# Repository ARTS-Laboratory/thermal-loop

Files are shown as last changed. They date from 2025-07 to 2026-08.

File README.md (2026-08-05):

# CORE²S
## Control-Oriented Research Environment for Energy Systems

A physical and digital testbed for experimenting with thermal, fluid, and control behavior in energy systems. It supports model calibration, dynamic synchronization, and validation of control strategies using measured loop data and simulation.

<p align="center">
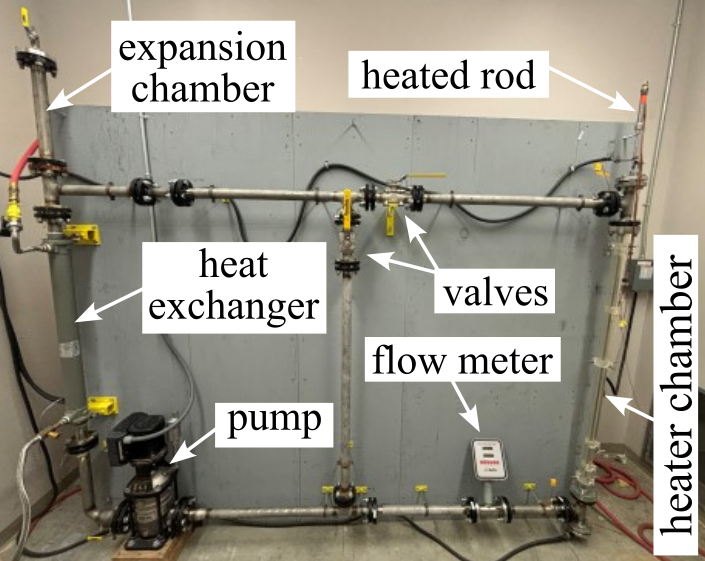
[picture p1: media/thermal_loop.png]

</p>
<p align="center"> Pressurized thermal loop with key components annotated.
</p>

## Licensing and Citation

[][cc-by-sa]

This work is licensed under a
[Creative Commons Attribution-ShareAlike 4.0 International License][cc-by-sa].

[cc-by-sa]: http://creativecommons.org/licenses/by-sa/4.0/
[cc-by-sa-image]: https://licensebuttons.net/l/by-sa/4.0/88x31.png
[cc-by-sa-shield]: https://img.shields.io/badge/License-CC%20BY--SA%204.0-lightgrey.svg

Cite as:

@Misc{ARTSLabControlOrientedResearch,
  author = {{ARTS-L}ab},  
  note   = {Accessed: 20xx-xx-xx},   
  title  = {Control-Oriented Research Environment for Energy Systems},   
  year   = {20xx},   
  groups = {{ARTS-L}ab},   
  url    = {https://github.com/ARTS-Laboratory/core2s},   
}

<p align="center">
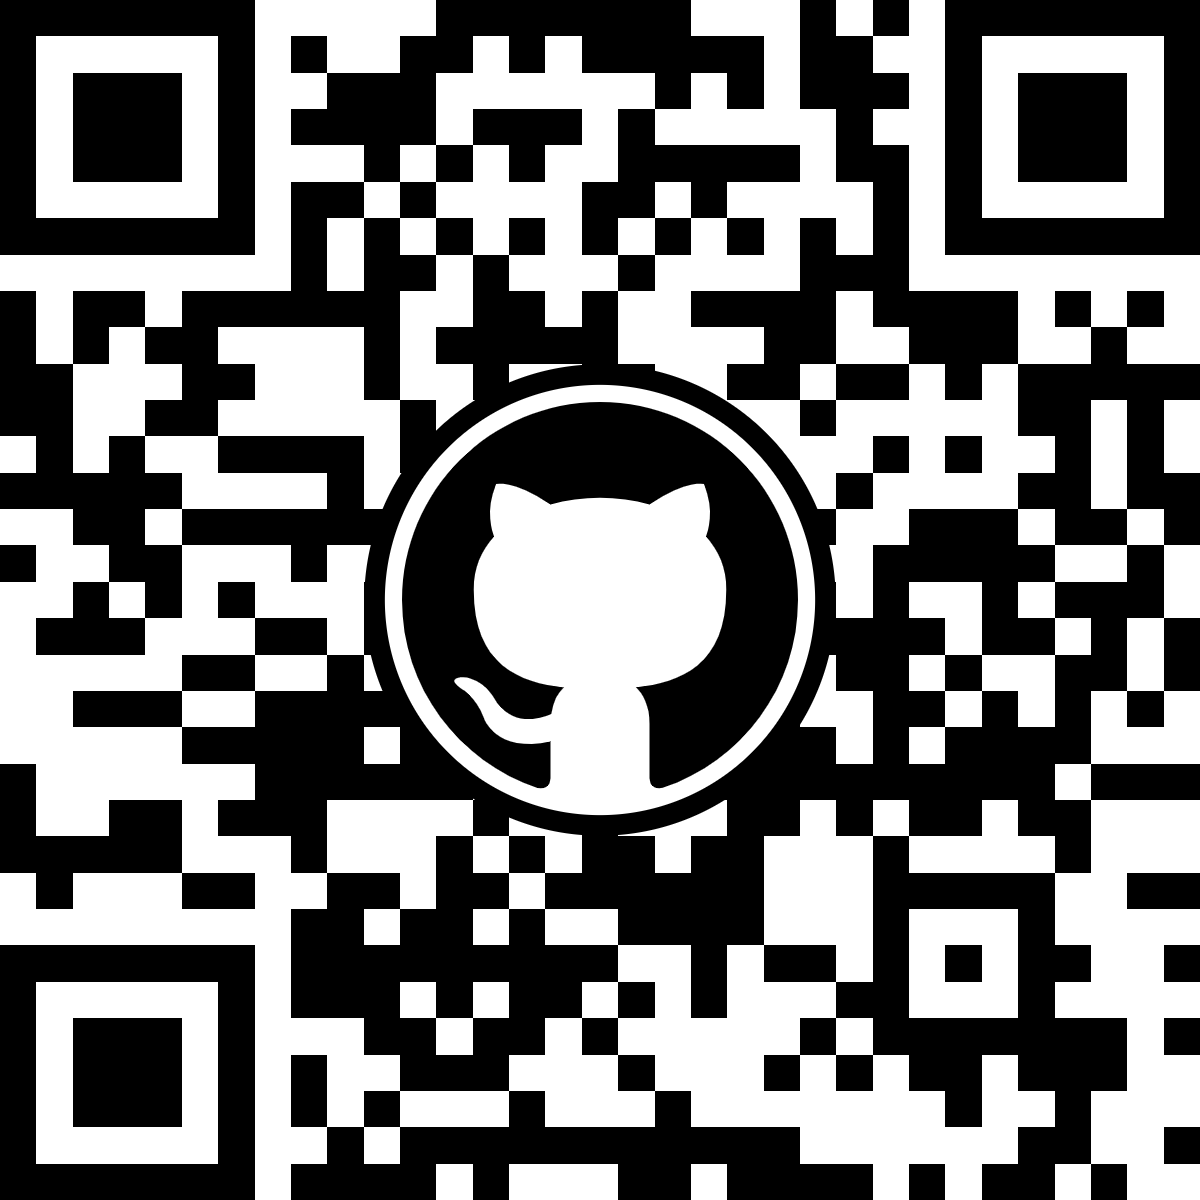
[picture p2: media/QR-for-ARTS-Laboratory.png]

</p>
<p align="center">
QR code for repo.

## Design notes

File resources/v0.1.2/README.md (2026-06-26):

# v0.1.1

## CAD

## Data

## Sesign Documents

## Controller

## Simulations

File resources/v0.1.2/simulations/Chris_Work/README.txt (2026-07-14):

This folder contains the work of Chris Heaps on simulations of the SMR loop in Simscape. Versions are detailed as follows:

v1.0.1: First working model, uses constant energy supply to the fuel rod and constant city side water supply temperature

v1.0.2: Adds transient initial conditions for the loop. This includes a function to represent slight variations in the city water supply temperature. Also adds a direct voltage input for the heat supplied to the simulated fuel rod, just as the actual loop has.

v1.0.3: Retains the same features as previous model and adds controllable power supply for varying voltages. This is the most stable and accurate version of the model so far. Longest test has been twelve hours and it maintained the cutoff temperature almost perfectly throughout the main loop for the entire test.

Next versions: Redesign for incorporation with SpeedGoat real time target computer.

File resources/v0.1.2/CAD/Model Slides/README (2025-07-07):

In this folder, there are the slides to the final model as well as the extension pipes we used to expand our current Thermal Loop System. We have included both the threaded and welded versions of the one foot extension pipe.

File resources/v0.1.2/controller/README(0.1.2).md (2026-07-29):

# Controller Code

* The LabVIEW Controller code
* **LabVIEW\_SMR\_V1:**
* 
* First iteration of the LabVIEW for the thermal loop, completed 6/24/26.
* 
* Only goals of this was to confirm that values are being read from the heat exchanger, all 7 pressure transducers, and all 8 thermocouples.
* 
* Problems to fix:
* 
* Incorrect flow meter value (around 0.2 GPM too high)
* 
* Incorrect P4 measurement, as well as possibly others incorrect as well
* 
* Temp. And Pressure graphs not reading history of each different sensor, instead combining them into one function
* 
* No labels on the array of outputs
* 
* To be added in future iterations:
* 
* proportional valve showing and PID control established
* 
* Possibly flow meter in main loop wired to show readings as well (will need to investigate further to see about buying a new one or if able to wire to current)
* 
* &#x20;
* 
* **LabVIEW\_SMR\_V2:**
* 
* Focused on fixing problems from first iteration:
* 
* Pressure not reading correctly (deep dive into P4 wiring still required, possibly not a LabVIEW problem)
* 
* Graphs fixed
* 
* Compensator attempted to be added to fix incorrect flowmeter output, although needs to be fine tuned (possibly with a function?)
* 
* Arrays fixed so that labels for data points are visible

**LabVIEW\_SMR\_V3:**

Focused on fixing problems from second iteration:

Pressure reading for P4 fixed

Temperature and Pressure readings split into:

&#x09;Main loop (loop excluding heat exchanger) average pressure/temp, heat exchanger average pressure/temp, and overall (loop + heat exch.)

&#x09;average pressure/temp

Still a problem with flowmeter not being calibrated correctly, will need to be fixed in future iterations

For now, looks like flowmeter is only data reading that is incorrect.

Future iterations: adding proportional valve and working through control for it

&#x09;		adding a storage system, where the data is stored directly into a file for future use.

**LabVIEW\_SMR\_V4:**

First iteration with rudimentary Proportional Valve control attempted

control DOES NOT WORK!

**LabVIEW\_SMR\_V4.5:**

Second iteration with Proportional Valve control attempted. still does not work, but diagnosed the physical controller as the problem

**LabVIEW\_SMR\_V5:**

No proportional valve added, only attempted to create a data storage system, throwing data into 3 different .csv 's: one for temp, one for pressure, one for heat exchanger flow.

Broke everything, does not work, currently in progress.

**LabVIEW\_SMR\_V6:**

Complete data acquisition and automatic file storage

Data is stored into SMR\_Logs folder on local computer in c004. If using a different computer, file path on the front panel must be changed to your specific location.

**LabVIEW\_SMR\_V6.5:**

Changed V6 so that there is now one file path name instead of three. all data is now saved into the GitHub folder data -> 001 -> run\_\[data of test]. Paired with Python, python will also insert plots of the data directly into this run folder.

**LabVIEW\_SMR\_V6.75:**

Changed V6.5 so that warning lights are added: 3 different red lights showing if max pressure was reached, max temp was reached, or max voltage was reached (respectively). All have controllable thresholds via the front panel.

Added a steady state indicator, with a controllable threshold. Green light turns on when steady state is reached, which is calculated via (deg C/min).
To be added in next version: voltage readings via new cDAQ NI 9229.

**LabVIEW\_SMR\_V7:**

First version with working (manual) proportional valve control. Although rudimentary, valve can be controlled via "P-Valve Command Voltage) from 0-10V.

For next iteration:

&#x09;add emergency shut off (if temp reaches \_\_, open p-valve all the way, etc.)

&#x09;add PID control for p-valve

&#x09;add voltage reading (when cables acquired)

**LabVIEW\_SMR\_V7.1:**

Rudimentary PID control for P-valve established. On/Off switch to determine whether manual or PID control takes over p-valve voltage.

Next iteration:

&#x09;tune PID and limit the p-valve (flow meter only goes to 5GPM, need to limit how far the valve opens)

**LabVIEW\_SMR\_V7.2:**

Nothing with valve changed.

Steady state indicator fully upgraded; works like this:

&#x09;When running, system waits 5 minutes for system to heat up

&#x09;After 5 minutes, the system calculates the maximum dT/dt in that 5 minute window

&#x09;Maximum dT/dt is multiplied by 0.01 (1%)

&#x09;1% of the maximum dT/dt is considered to be the steady state threshold

&#x09;Loop continues to run, data continues to collect. When \[current dT/dt] < \[steady state threshold], system is considered to be in steady state.

**LabVIEW\_SMR\_V7.3: CURRENT BEST MODEL**

Revamped front panel to make it easier to interpret data as system is running. Also better grouping of indicators.

**LabVIEW\_SMR\_V7.5: CURRENT BEST MODEL**

Added indicator for voltage across rod. DO NOT TRUST THE POWER SUPPLY READINGS, ONLY LABVIEWS: PSU indicates higher voltage than what is physically going across rod; resistance and general voltage drop results in about 1-1.5V lost to the rod.

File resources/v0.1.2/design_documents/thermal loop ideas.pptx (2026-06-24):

## SMR Thermal Loop Ideas

Austin Downey

## The main idea

Keep it,
- Safe
- Simple
- Easy
- Clean

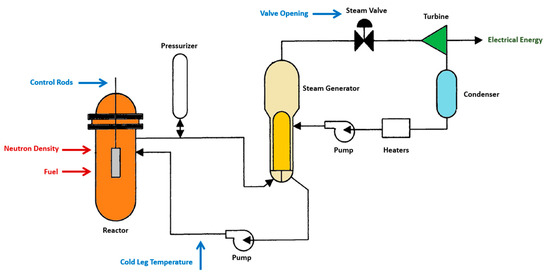
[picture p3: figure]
Energies 15 06588 g005 550

Basic idea, from the paper “Real-Time Simulation of a Small Modular Reactor in-the-Loop within Nuclear-Renewable Hybrid Energy Systems”
https://www.mdpi.com/1996-1073/15/18/6588

## Our version

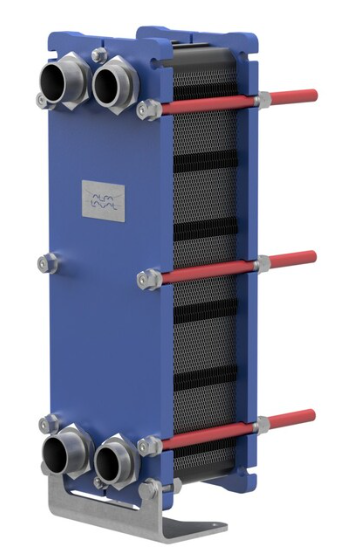
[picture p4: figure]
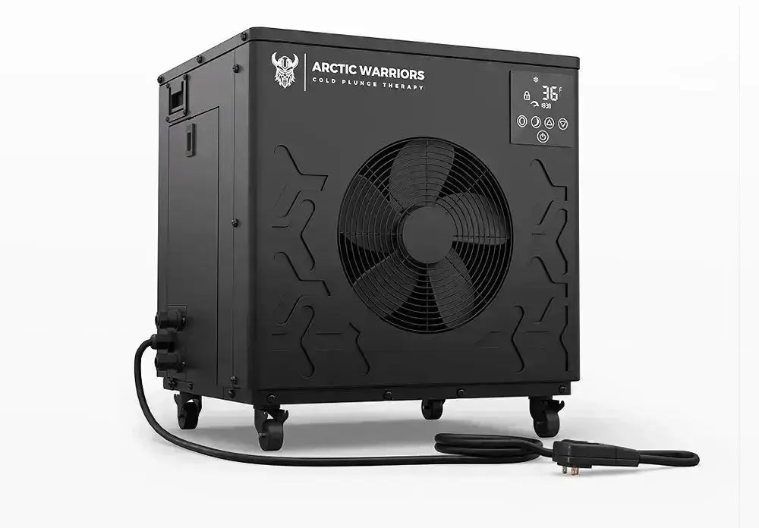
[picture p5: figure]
Arctic Warrior 0.5 HP Advanced Water Chiller Arctic Warriors

chiller

Plate heat exchanger

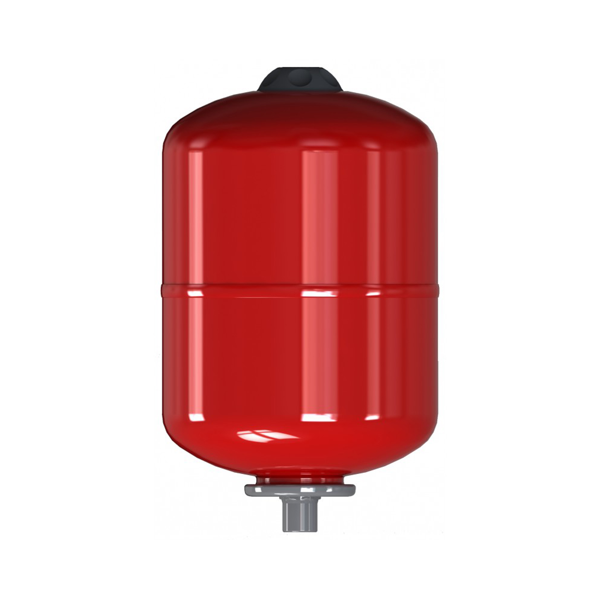
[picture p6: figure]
Varem 90 psi Max (20 psi Precharged) 10.6 gal. Expansion Water Heater Tank, 0.75 in. Inlet Diameter 1581106

pressure tank

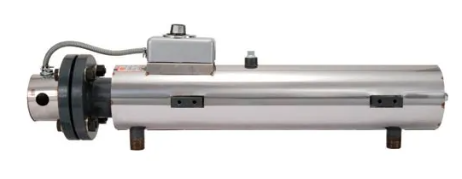
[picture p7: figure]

Inline heater

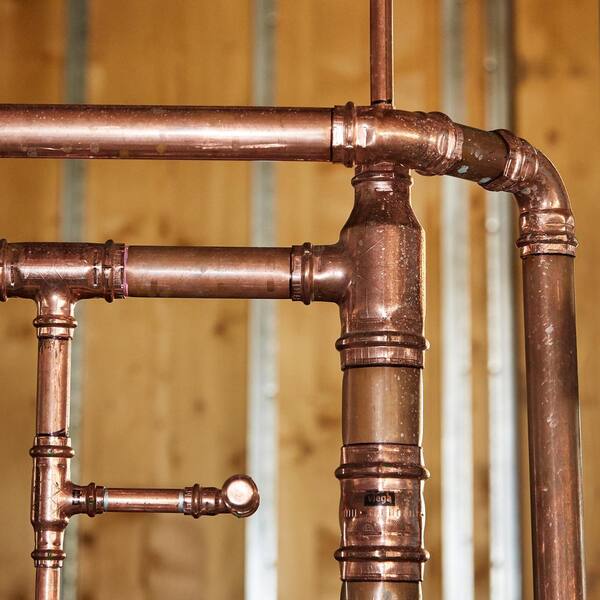
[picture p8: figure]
Viega 77477 ProPress 2 in. Press Copper Tee

2” pro press line

## Hardware we have for use

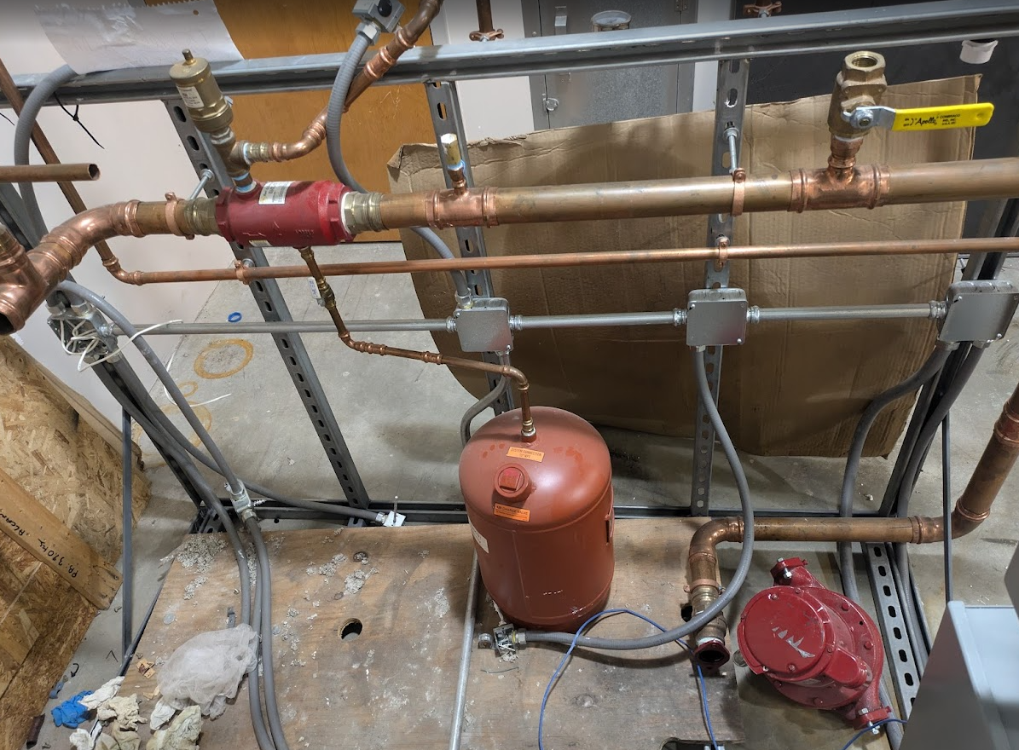
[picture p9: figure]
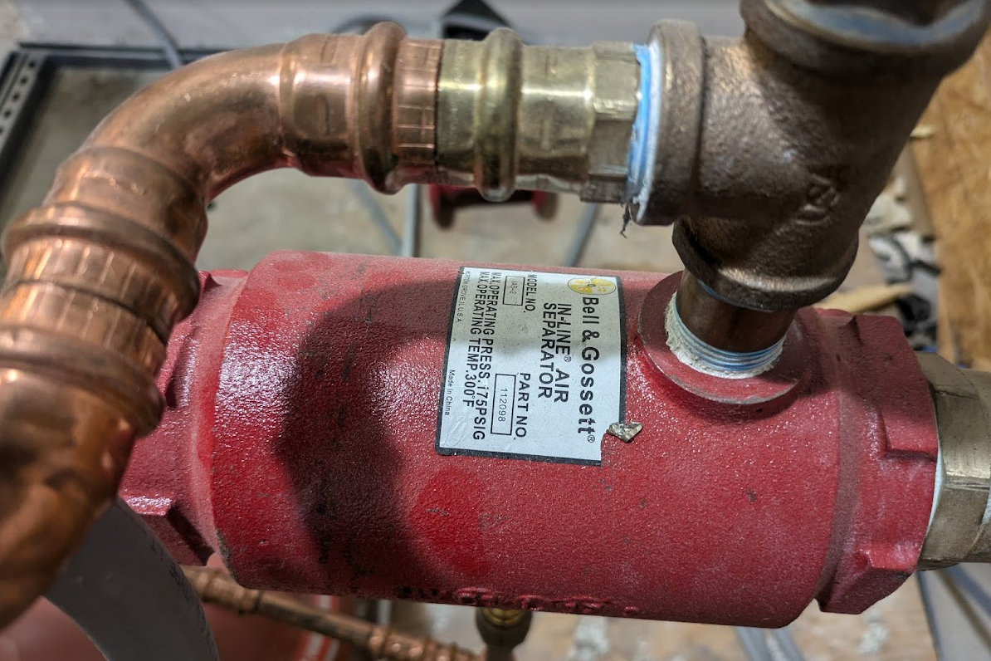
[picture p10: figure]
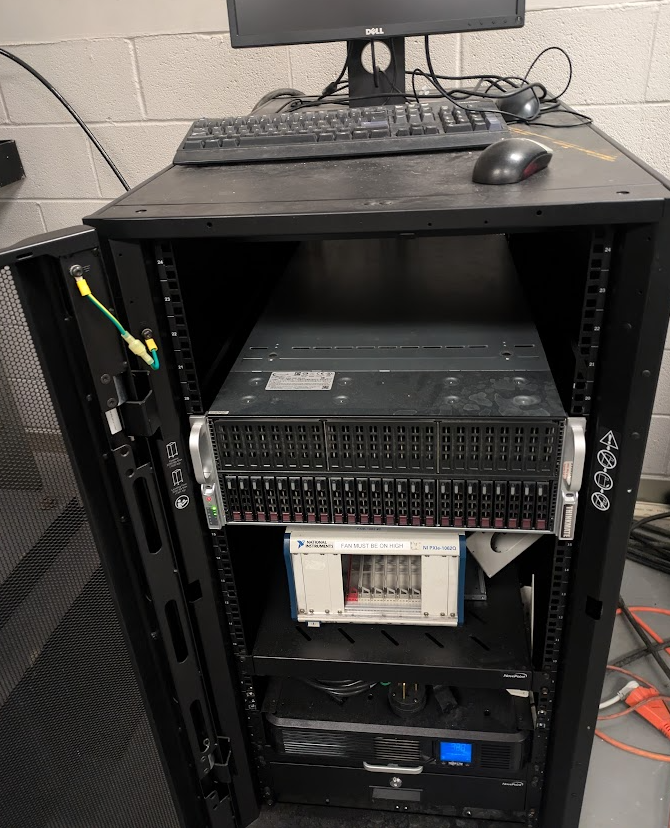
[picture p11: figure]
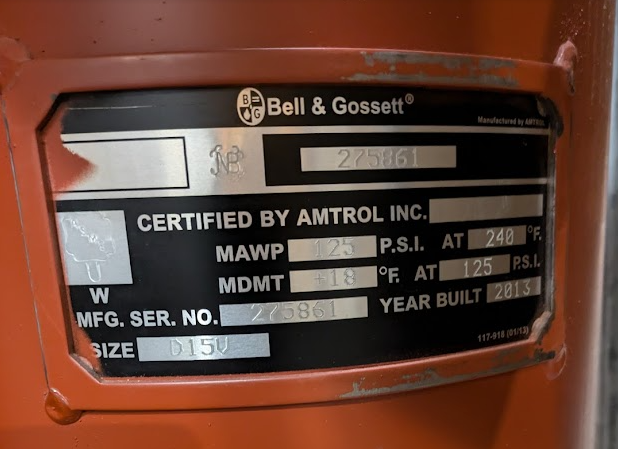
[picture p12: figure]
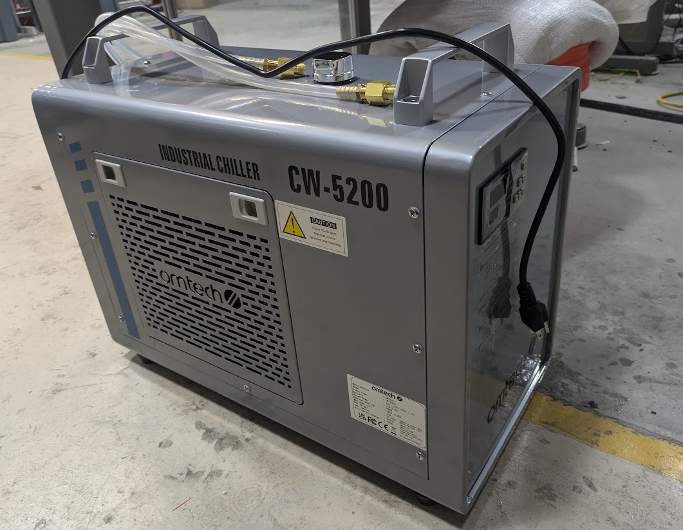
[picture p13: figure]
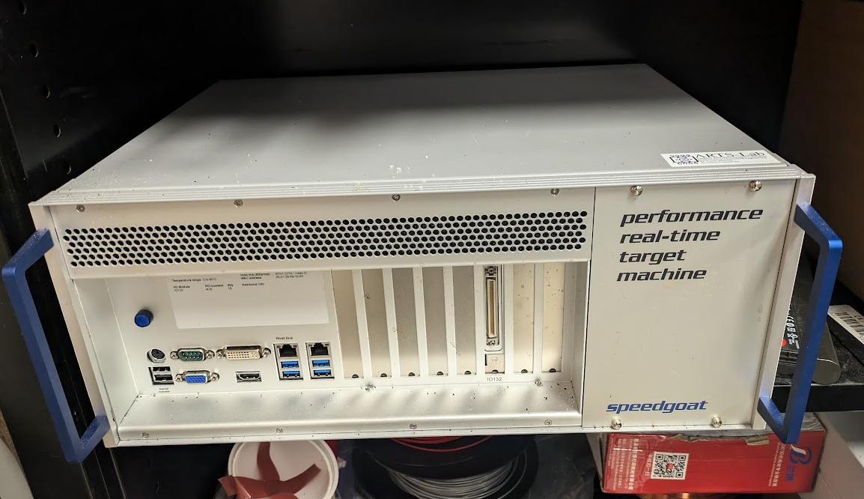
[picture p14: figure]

## Hardware we have for use

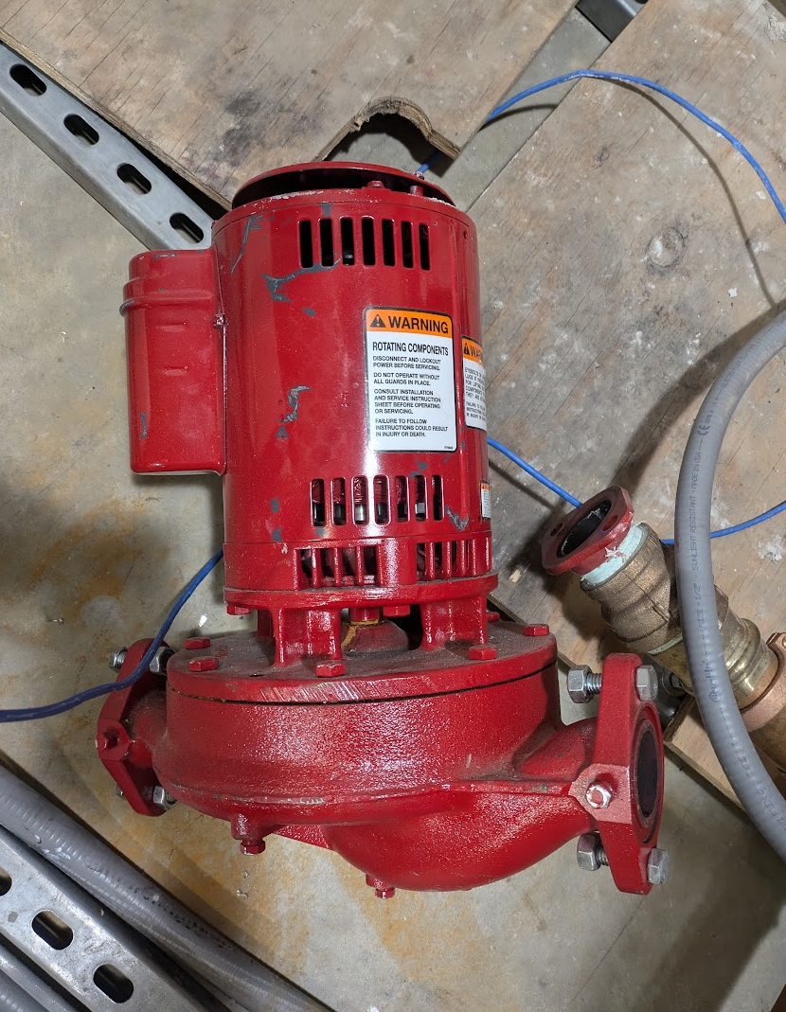
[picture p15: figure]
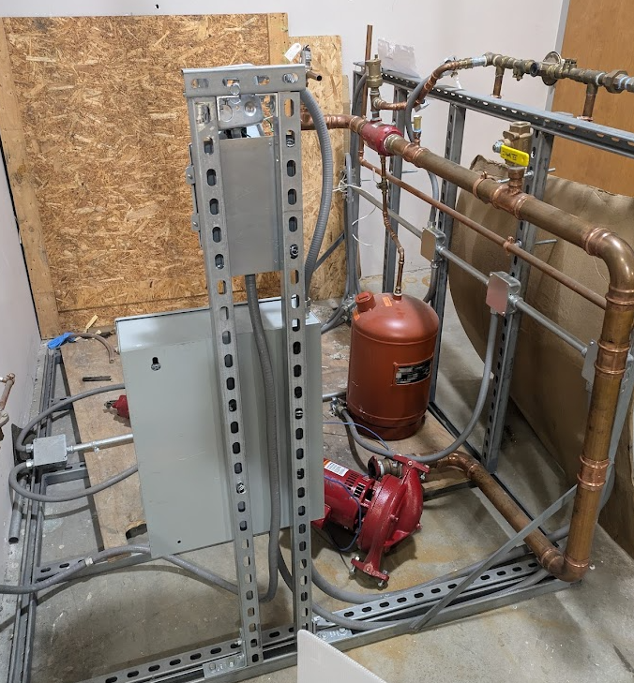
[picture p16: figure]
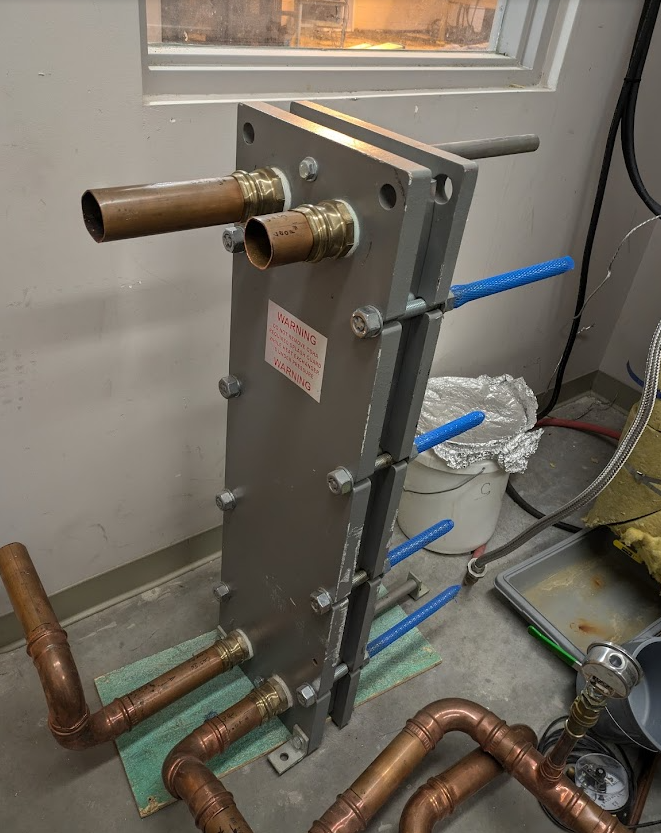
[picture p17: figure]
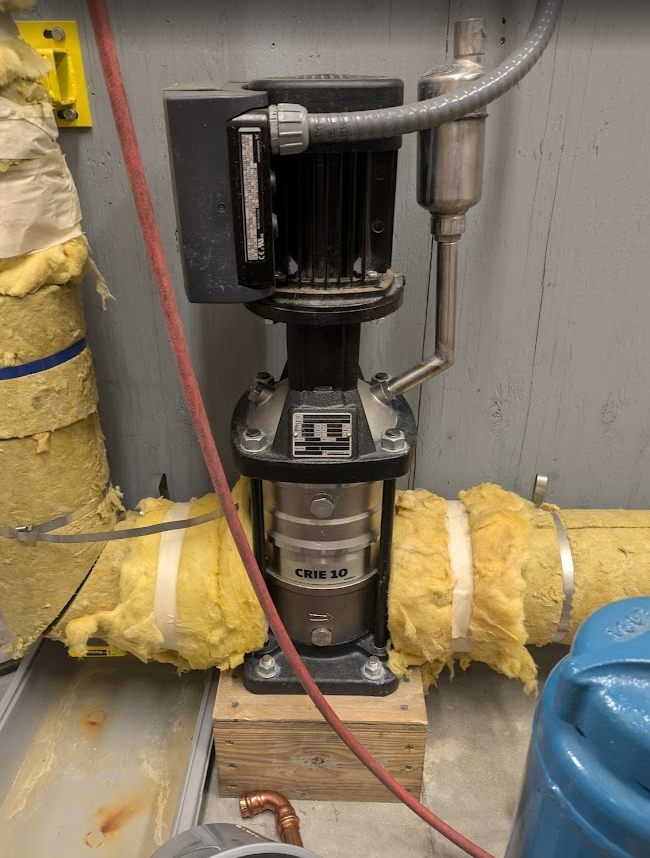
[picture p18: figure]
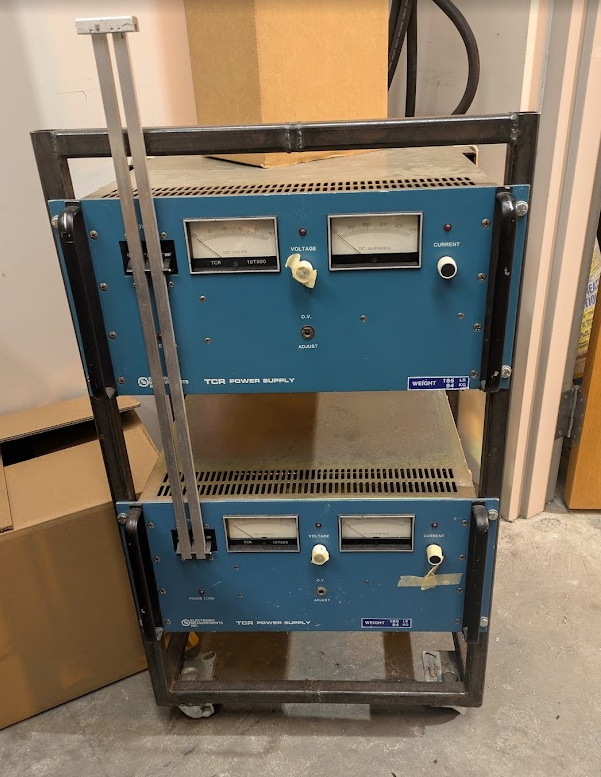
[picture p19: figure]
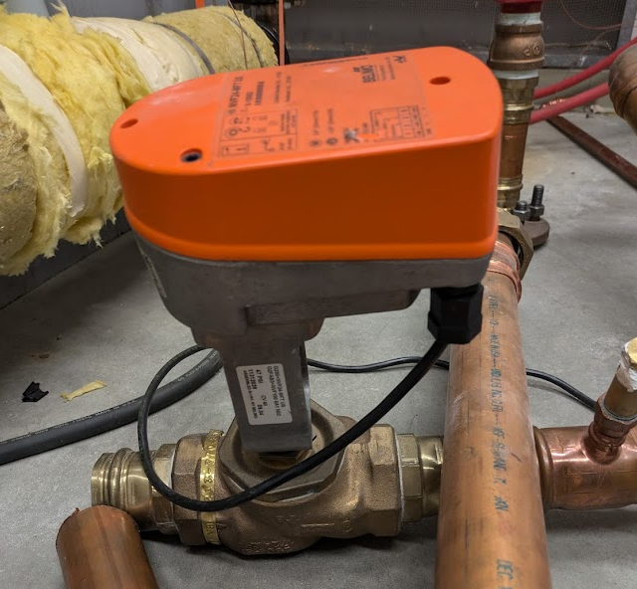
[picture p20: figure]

## Thank You for Your Time

- Name: Ausitn Downey
- Title: Associate Professor
- Email: austindowney@sc.edu
- Lab GitHub: github.com/arts-laboratory

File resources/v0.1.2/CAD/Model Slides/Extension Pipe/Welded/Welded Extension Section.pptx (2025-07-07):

## Welded Extension Section

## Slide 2

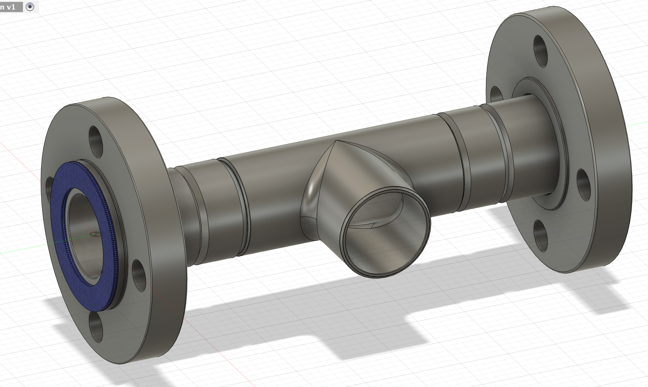
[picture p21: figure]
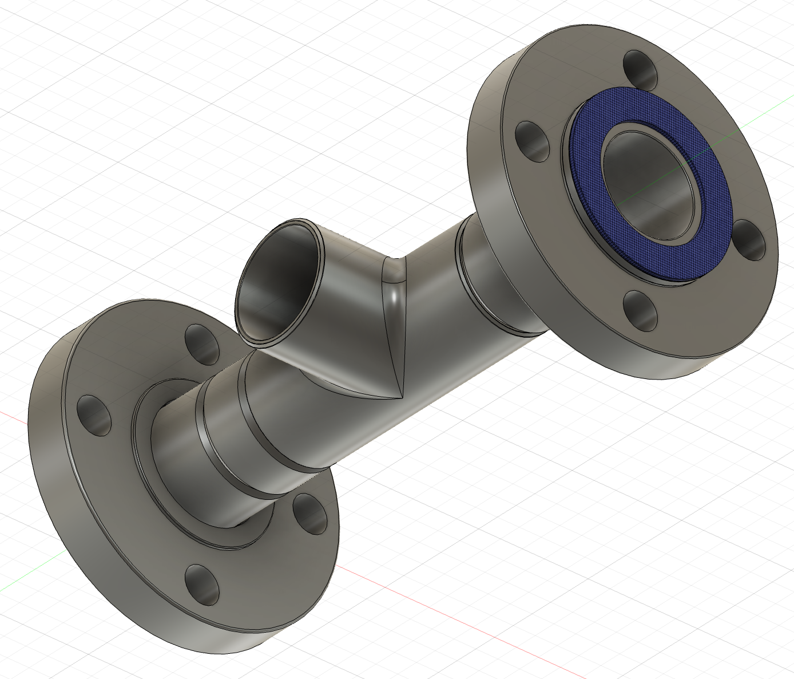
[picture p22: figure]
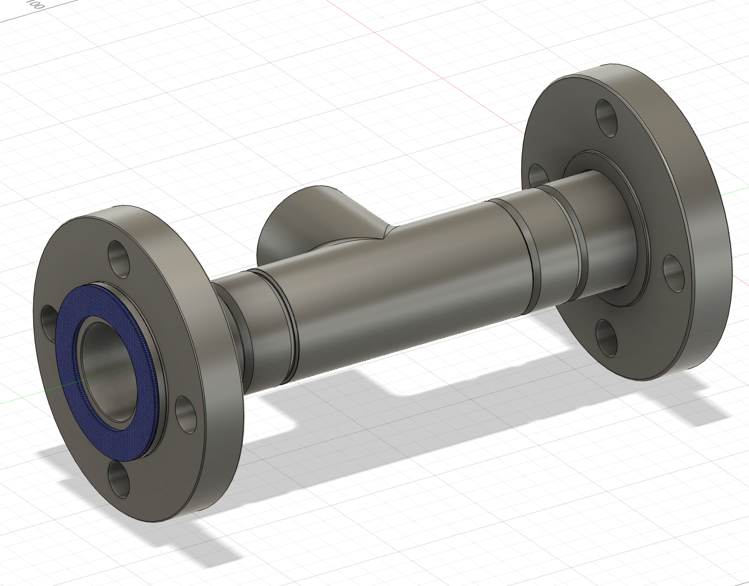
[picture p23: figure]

Complete Welded Extension

Cost
(Flanges) 2 x $63.10 = $126.2
(Pipes) 2 x $58.98 = $117.96
(Flng Pipes) 2 x $75.45 = $150.90 +
(T-Pipe)1 x $44.86 = $44.86
(Seal) 2 x $10.97 = $21.94
Total cost ========== $461.86

Length = 267.4 mm

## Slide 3

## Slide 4

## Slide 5

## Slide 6

Welded Flange

Cost
$63.10 each
2 flanges used
Total = $126.2

Welded Flange Grainger Link (https://www.grainger.com/product/Pipe-Flange-Slip-On-Flange-60WJ84)

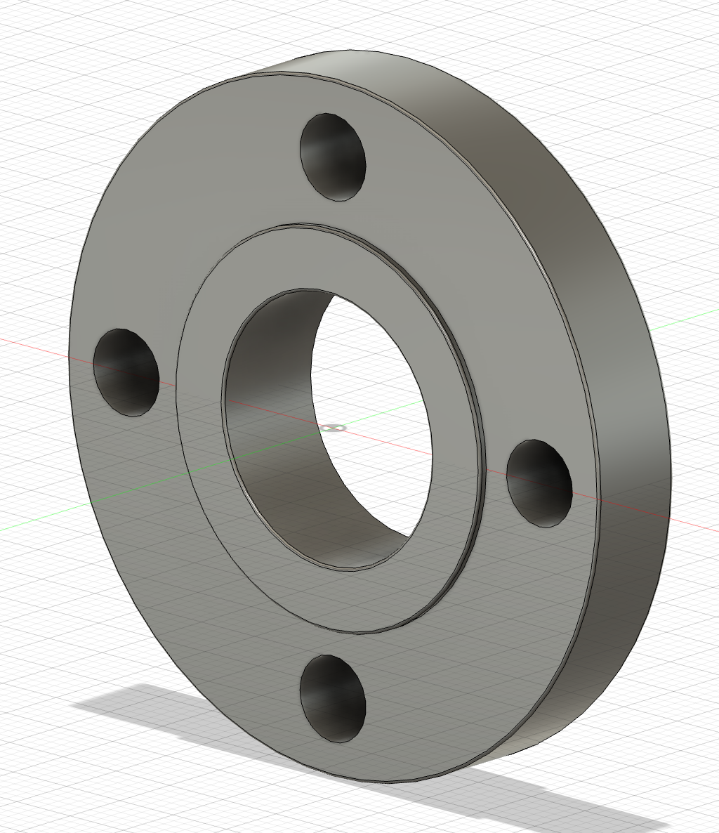
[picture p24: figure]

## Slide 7

1 ½ Weld Extension Pipe

Cost
$58.98 each
2 pipes used
Total = $117.96
This pipe is a custom-cut 23.8 mm
piece a 1 ft long pipe

Welded pipe Grainger Link (https://www.grainger.com/product/Nipple-304-Stainless-Steel-782G43)

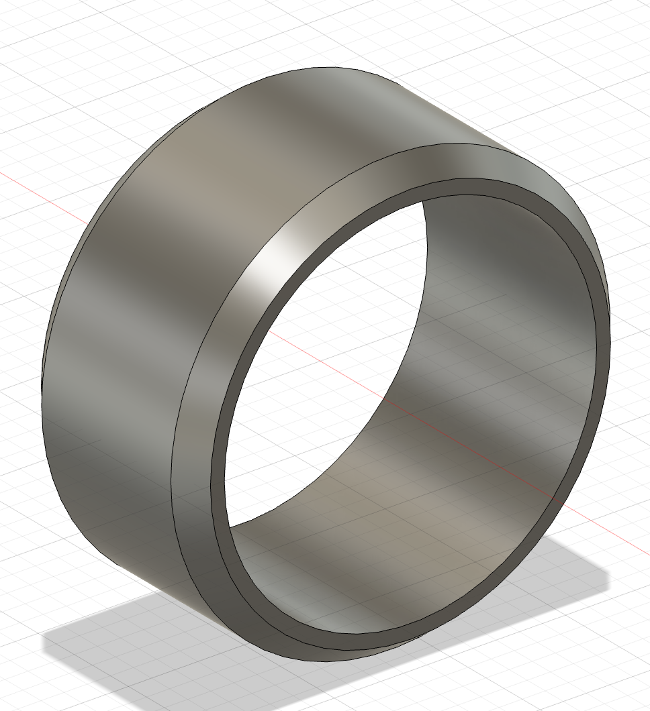
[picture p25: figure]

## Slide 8

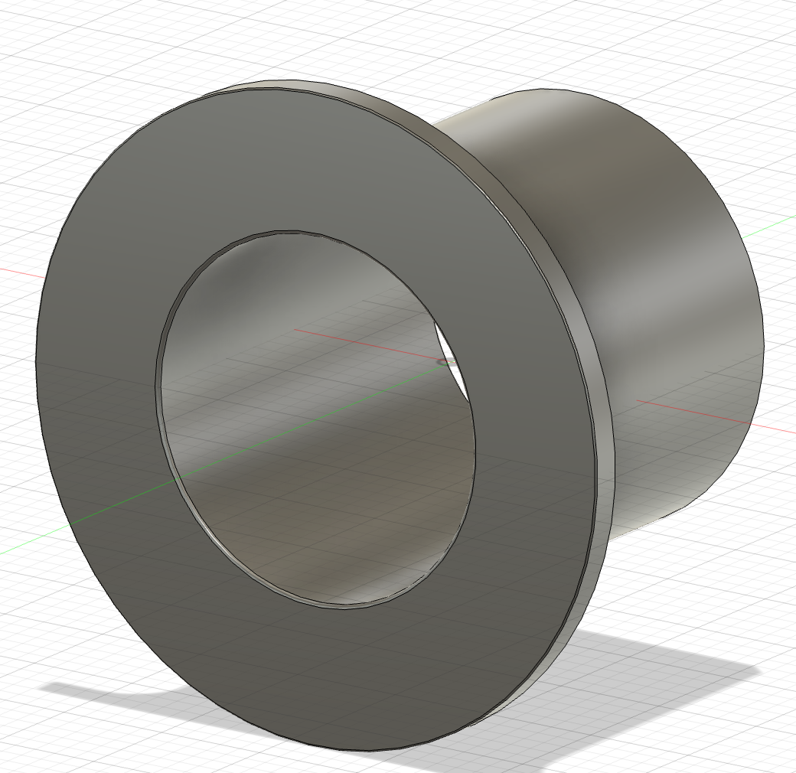
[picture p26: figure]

Flange Step End Pipe

Cost
$75.45 each
2 Flange Pipes used
Total = $150.90

Step End Pipe Graigner Link (https://www.grainger.com/product/Stub-End-Type-A-304L-Stainless-1RTU2)


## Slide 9


Welded T-Pipe

Cost
$44.86 each
1 T-Pipe used
Total = $44.86

Welded T-Pipe Grainger Link (https://www.grainger.com/product/Tee-304L-Stainless-Steel-1RTR2)


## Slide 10

Average Flange Blue Seal

Cost
$10.97 each
2 seals used
Total = $21.94


Flange Seal Grainger Link (https://www.grainger.com/product/GARLOCK-Ring-Flange-Gasket-Class-150-38VR20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)

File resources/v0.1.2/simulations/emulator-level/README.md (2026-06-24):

# Multi-domain Models

## Emulator Level
* A Simscape model of the thermal loop as built in C004G
* Used for developing a DT of the thermal loop

### What follows if from MAtt's upload. 
* Update as needed. 
**PRESSURIZED WATER REACTOR FOR A SMALL MODULAR REACTOR**

The models here conatain variations of a thermal loop for a pressurized water reactor system in a small modular reactor. 
The thermal loop consists of 2 main cycles;

~primary - the loop containg the fluid flow through the reactor to the steam generator

~secondary - the loop used to generate electricity from the steam in the steam generator


citation link; https://www.nrc.gov/reading-rm/basic-ref/students/animated-pwr.html 

[text](../README.md)

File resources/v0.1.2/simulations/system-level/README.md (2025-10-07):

# System Level
* An expansion of the emulator loop to include perifierity components like reactors, steam generators, and turbines
* Used for developing a system-level understanding of how the emulator interacts with the broader grid.

* 

This is the part of the image highlighted in blue

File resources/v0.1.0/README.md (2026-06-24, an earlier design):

# v0.1.0
* All files for the initial system
* Covers work done in the summer of 2025-june 2026
* Has a collectoin of CAD files, data, code, etc.

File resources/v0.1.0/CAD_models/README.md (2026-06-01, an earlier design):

# CAD models

* V0.1.0 - CAD models done in the summer of 2025 by summer High School Students 
* V0.1.1 - CAD models integrated into Inventor Ecosystem

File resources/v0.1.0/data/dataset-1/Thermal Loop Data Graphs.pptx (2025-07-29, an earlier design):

## Thermal Loop Data Graphs

## Test #1: Pump Heat up (vo)


PDF name- Full_PumpHeat(HeatExchange.flow.vo)

- Middle valve open
- Upper valve open
- Heat exchange increments of 0.5 gal/min every 30 mins starting at hour 6

Raw Data File name
PumpHeat_HeatExhanger.flow.vo

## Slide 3

Test #1: Additional close up data


PDF name- PumpHeat_up_6_hours.vo


0.511 gal/min flow rate

1.022 gal/min flow rate

1.500 gal/min flow rate

2.001 gal/min flow rate

PDF name- PumpHeat_HeatExchange.flow.vo

## Test #2: Pump Heat up (vc)


PDF name- Full_PumpHeat(HeatExchange.0.5flow.vc)

- Middle valve closed
- Upper valve open
- Heat exchanger 0.5 gal/min flow rate at 6 hours

Raw Data File name PumpHeat_HeatExchanger.0.5flow.vc

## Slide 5

Test #2: Additional close up data


PDF name- PumpHeat_HeatExchange_0.5gal._flow.vc


PDF name- PumpHeat_up_6_hours.vc

0.511 gal/min flow rate

## Test #3: Rod Heat up (vc)


PDF name- Full_RodHeat(HeatExchange.flow.vc)

- Middle Valve closed
- Upper Valve open
- Heat Exchanger 0.5 gal/min at 4.5 hours

Raw Data File name
RodHeat_NewData

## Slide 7

Test #3: Additional close up data


PDF name- RodHeat_0.5_gal_flow.vc


PDF name- RodHeat_6_hours.vc

0.511 gal/min flow rate

## Test #4: Rod Heat up (vo)


PDF name- Full_RodHeat.vo(CoolDown)

- Middle Valve open
- Upper Valve open
- At 4.45 hours Pump and Rod turned off

Raw Data File name
RodHeat_vo_cool_NewData

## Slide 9

Test #4: Additional close up data


PDF name- RodHeat_CoolDown.vo

PDF name- RodHeat_up.vo

Pump and Rod turned off

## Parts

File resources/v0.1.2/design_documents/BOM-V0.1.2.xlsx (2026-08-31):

Internal Part Name | MFR / Vendor Description | MFR Part Number | Quantity | Individual Cost | Total Cost | Notes | Vendor 1 | Vendor 2 | Vendor 3 | Vendor 4
Wire Duct | Thomas & Betts - 2 X 2 X 72 IN GRAY WIDE SLOT WIRING DUCT | MSC Direct | 92012988 | 1 | 25.58 | $25.58 |  | https://www.mscdirect.com/product/details/92012988?rItem=92012988
Hex Screw | Value Collection - Hex Head Cap Screw: 5/8-11, 3" Length Under Head, Grade 2 Steel, Zinc Finish | MSC Direct | 67436964 | 10 | 1.71 | $17.10 |  | Value Collection - Hex Head Cap Screw: 5/8-11, 3" Length Under Head, Grade 2 Steel, Zinc Finish | MSC Direct (https://www.mscdirect.com/product/details/67436964?rItem=67436964)
Hex Nut | Value Collection - Hex Nut: 5/8-11, Grade 2 Steel, Bright/Uncoated Finish | MSC Direct | 67473967 | 10 | 0.47 | $4.70 |  | Value Collection - Hex Nut: 5/8-11, Grade 2 Steel, Bright/Uncoated Finish | MSC Direct (https://www.mscdirect.com/product/details/67473967?rItem=67473967)
Wire Duct | 1.50" x 0.75" x 6' White Lead-Free PVC Panduct® Narrow Slot Wiring Duct | Fastenal | 99176795 | 6 | 5.45 | $32.70 |  | 1.50" x 0.75" x 6' White Lead-Free PVC Panduct® Narrow Slot Wiring Duct | Fastenal (https://www.fastenal.com/product/details/99176795)
Wire Duct | 1 1/2 in Nom Wd, 1.3 in Slot Ht, Wiring Duct - 53UJ14|TYD15X2NPG6 - Grainger | 53UJ14 | 3 | 25.94 | $77.82 |  | 1 1/2 in Nom Wd, 1.3 in Slot Ht, Wiring Duct - 53UJ14|TYD15X2NPG6 - Grainger (https://www.grainger.com/product/53UJ14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)
Duct Cover | PVC, 72 in Lg, Wiring Duct Cover - 53UH83|TYD15CPG6 - Grainger | 53UH83 | 3 | 10.41 | $31.23 |  | PVC, 72 in Lg, Wiring Duct Cover - 53UH83|TYD15CPG6 - Grainger (https://www.grainger.com/product/53UH83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)
Threaded Flange | Flange, 304 Stainless Steel, Metal Pipe Flange - 4WPV1|4381001040 - Grainger | 4WPV1 | 1 | 93.93 | $93.93 |  | Flange, 304 Stainless Steel, Metal Pipe Flange - 4WPV1|4381001040 - Grainger (https://www.grainger.com/product/Metal-Pipe-Flange-Flange-4WPV1)
Plastic Bushing | Bushing, 1 1/2 in x 3/4 in Fitting Pipe Size, Pipe Straight - 1MKC2|RB150-075 - Grainger | 1MKC2 | 1 | 5.99 | $5.99 |  | Bushing, 1 1/2 in x 3/4 in Fitting Pipe Size, Pipe Straight - 1MKC2|RB150-075 - Grainger (https://www.grainger.com/product/1MKC2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)
Brass Tee | PARKER, Tee, 3/4 in x 3/4 in x 3/4 in, Metal Pipe Tee - 13Y864|VS2225P-12 - Grainger | 13Y864 | 1 | 41.22 | $41.22 |  | PARKER, Tee, 3/4 in x 3/4 in x 3/4 in, Metal Pipe Tee - 13Y864|VS2225P-12 - Grainger (https://www.grainger.com/product/PARKER-Metal-Pipe-Tee-Tee-13Y864)
Compression Fitting | PARKER, 1/2 in OD x 3/4 in pipe Size, Compression x MNPT, Compression Fitting Adapter - 20YY84|8MSC12N-B - Grainger | 20YY84 | 1 | 60.89 | $60.89 |  | PARKER, 1/2 in OD x 3/4 in pipe Size, Compression x MNPT, Compression Fitting Adapter - 20YY84|8MSC12N-B - Grainger (https://www.grainger.com/product/PARKER-Compression-Fitting-Adapter-20YY84)
DIN Terminals |  | N/A | 1 | 27.83 | $27.83 |  | N/A
Control for P-Valve | Dig. control electroncis for prop.valves | 316533 | 1 | 370 | $370.00 |  | Dig. control electroncis for prop.valves (https://www.burkert-usa.com/en/products/proportional-valves/controllers/316533)
PWM Control for P-Valve | Type 8605 - PWM control electronics for electromagnetic proportional valves | 316530 | 1 | 312 | $312.00 |  | Type 8605 - PWM control electronics for electromagnetic proportional valves (https://www.burkert-usa.com/en/type/8605)
Controller Plug Connect. | Plug connection form A | 314802 | 1 | 5.9 | $5.90 |  | Plug connection form A (https://www.burkert-usa.com/en/products/solenoid-valves/accessories/cable-plugs/314802)
Proportional Valve | 2/2-way-proportional valve | 164598 | 1 | 1610 | $1610.00 |  | 2/2-way-proportional valve (https://www.burkert-usa.com/en/products/proportional-valves/general-purpose-proportional-valves/164598)
Cable | 76402TS 0081000 Belden Inc. | Multiple Conductor Cables | DigiKey | 135-76402TS0081000-DS-ND | 25 | 3.97 | $99.25 |  | 76402TS 0081000 Belden Inc. | Multiple Conductor Cables | DigiKey (https://www.digikey.com/en/products/detail/belden-inc/76402TS-0081000/8121749?gclsrc=aw.ds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)
cDAQ |  | N/A` | 1 | 839.97 | $839.97 |  | N/A
Wire Stripper | JIC-2030 Jonard Tools | Wire Strippers and Accessories | DigiKey | K604-ND | 2 | 14.02 | $28.04 |  | JIC-2030 Jonard Tools | Wire Strippers and Accessories | DigiKey (https://www.digikey.com/en/products/detail/jonard-tools/JIC-2030/2308356?so=97133380&content=productdetail_row)
Wire Crimper | 34055 Klein Tools, Inc. | Crimpers, Applicators, Presses | DigiKey | 1742-34055-ND | 1 | 33.58 | $33.58 |  | 34055 Klein Tools, Inc. | Crimpers, Applicators, Presses | DigiKey (https://www.digikey.com/en/products/detail/klein-tools-inc/34055/24627409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)
Ferrule | 1161014 American Electrical Inc. | Terminal Block Wire Ferrules | DigiKey | 288-1001-ND | 250 | 0.12664 | $31.66 |  | 1161014 American Electrical Inc. | Terminal Block Wire Ferrules | DigiKey (https://www.digikey.com/en/products/detail/american-electrical-inc/1161014/266366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)
Monitor Mount | Bosch UMM-LW-20B Monitor Wall Mount (Fixed) UMM-LW-20B B&H Photo | BOUMMLW20B | 1 | 59 | $59.00 |  | Bosch UMM-LW-20B Monitor Wall Mount (Fixed) UMM-LW-20B B&H Photo (https://www.bhphotovideo.com/c/product/744102-REG/Bosch_UMM_LW_20B_UMM_LW_20B_Monitor_Wall_Mount.html)
Touch Screen Monitor | Dell P2424HT - LED monitor - 24" (23.8" viewable) - touchscreen - 1920 x 1080 Full HD (1080p) @ 60 Hz - IPS - 300 cd/m² - DELL-P2424HT - Computer Monitors - CDWG.com | 7568365 | 2 | 341.13 | $682.26 |  | Dell P2424HT - LED monitor - 24" (23.8" viewable) - touchscreen - 1920 x 1080 Full HD (1080p) @ 60 Hz - IPS - 300 cd/m² - DELL-P2424HT - Computer Monitors - CDWG.com (https://www.cdwg.com/product/dell-p2424ht-led-monitor-full-hd-1080p-24/7568365?enkwrd=7568365)
Monitor | Dell Pro E2425HM - LED monitor - Full HD (1080p) - 24" - DELL-E2425HM - Computer Monitors - CDWG.com | 8323512 | 2 | 108.02 | $216.04 |  | Dell Pro E2425HM - LED monitor - Full HD (1080p) - 24" - DELL-E2425HM - Computer Monitors - CDWG.com (https://www.cdwg.com/product/dell-pro-e2425hm-led-monitor-full-hd-1080p-24/8323512?enkwrd=8323512)
Monitor Mount | Bosch UMM-LW-20B Monitor Wall Mount (Fixed) UMM-LW-20B B&H Photo | BOUMMLW20B | 5 | 59 | $295.00 |  | Bosch UMM-LW-20B Monitor Wall Mount (Fixed) UMM-LW-20B B&H Photo (https://www.bhphotovideo.com/c/product/744102-REG/Bosch_UMM_LW_20B_UMM_LW_20B_Monitor_Wall_Mount.html)
Thermocouple | TEMPCO, 32°F to 2,300°F /0°C to 1,260°C, Type K, Thermocouple Probe - 3AAA2|TTW00180 - Grainger | 3AAA2 | 4 | 20.99 | $83.96 |  | TEMPCO, 32°F to 2,300°F /0°C to 1,260°C, Type K, Thermocouple Probe - 3AAA2|TTW00180 - Grainger (https://www.grainger.com/product/3AAA2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)
Compression Fitting | TEMPCO, Compression Fitting, Compression Fitting - 5ZY28|FTGR-1019 - Grainger | 5ZY28 | 4 | 7.46 | $29.84 |  | TEMPCO, Compression Fitting, Compression Fitting - 5ZY28|FTGR-1019 - Grainger (https://www.grainger.com/product/5ZY28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)
NPT x MNPT | PARKER, Straight, 1/2 in x 1 in, Metal Pipe Straight - 13Y764|VS209P-16-8 - Grainger | 13Y764 | 4 | 13.23 | $52.92 |  | PARKER, Straight, 1/2 in x 1 in, Metal Pipe Straight - 13Y764|VS209P-16-8 - Grainger (https://www.grainger.com/product/13Y764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)
MNPT x NPT | PARKER, Straight, 1 in x 3/4 in, Metal Pipe Straight - 13Y763|VS209P-16-12 - Grainger | 13Y763 | 4 | 12.78 | $51.12 |  | PARKER, Straight, 1 in x 3/4 in, Metal Pipe Straight - 13Y763|VS209P-16-12 - Grainger (https://www.grainger.com/product/13Y763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)
NPT x NPT | Brass, 3/4 in Nominal Pipe Size, Pipe Nipple - 4DRC4|464-001X - Grainger | 4DRC4 | 4 | 9.99 | $39.96 |  | Brass, 3/4 in Nominal Pipe Size, Pipe Nipple - 4DRC4|464-001X - Grainger (https://www.grainger.com/product/4DRC4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)
Nipple | Brass, 3/4 in Nominal Pipe Size, Pipe Nipple - 1VGU6|464-040 - Grainger | 1VGU6 | 4 | 22.34 | $89.36 |  | Brass, 3/4 in Nominal Pipe Size, Pipe Nipple - 1VGU6|464-040 - Grainger (https://www.grainger.com/product/1VGU6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)
Nipple | Brass, 3/4 in Nominal Pipe Size, Pipe Nipple - 1VGU2|464-030 - Grainger | 1VGU2 | 4 | 16.89 | $67.56 |  | Brass, 3/4 in Nominal Pipe Size, Pipe Nipple - 1VGU2|464-030 - Grainger (https://www.grainger.com/product/1VGU2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)
90 Elbow | 90° Elbow, 3/4 in x 3/4 in, Metal Pipe Elbow - 1VER9|1VER9 - Grainger | 1VER9 | 2 | 21.79 | $43.58 |  | 90° Elbow, 3/4 in x 3/4 in, Metal Pipe Elbow - 1VER9|1VER9 - Grainger (https://www.grainger.com/product/1VER9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)
90 Elbow | 90° Elbow, 3/4 in x 1/2 in, Metal Pipe Elbow - 2CFF9|2CFF9 - Grainger | 2CFF9 | 2 | 19.86 | $39.72 |  | 90° Elbow, 3/4 in x 1/2 in, Metal Pipe Elbow - 2CFF9|2CFF9 - Grainger (https://www.grainger.com/product/2CFF9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)
Tee | Tee, 3/4 in x 3/4 in x 3/4 in, Metal Pipe Tee - 1VEZ5|1VEZ5 - Grainger | 1VEZ5 | 1 | 36.98 | $36.98 |  | Tee, 3/4 in x 3/4 in x 3/4 in, Metal Pipe Tee - 1VEZ5|1VEZ5 - Grainger (https://www.grainger.com/product/1VEZ5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)
Tee | Tee, 1/2 in x 1/2 in x 1/2 in, Metal Pipe Tee - 6RCZ8|6RCZ8 - Grainger | 6RCZ8 | 1 | 26.2 | $26.20 |  | Tee, 1/2 in x 1/2 in x 1/2 in, Metal Pipe Tee - 6RCZ8|6RCZ8 - Grainger (https://www.grainger.com/product/6RCZ8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)
Nipple | Brass, 1/2 in Nominal Pipe Size, Pipe Nipple - 1VGR6|463-040 - Grainger | 1VGR6 | 4 | 19.22 | $76.88 |  | Brass, 1/2 in Nominal Pipe Size, Pipe Nipple - 1VGR6|463-040 - Grainger (https://www.grainger.com/product/1VGR6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)
Copper Hanger | Swivel Loop, Copper-Plated Iron, Split-Ring Hanger - 22FP62|22FP62 - Grainger | 22FP62 | 6 | 2.48 | $14.88 |  | Swivel Loop, Copper-Plated Iron, Split-Ring Hanger - 22FP62|22FP62 - Grainger (https://www.grainger.com/product/22FP62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)
Copper Hanger | Swivel Loop, Copper-Plated Iron, Split-Ring Hanger - 22FP63|22FP63 - Grainger | 22FP63 | 6 | 3.21 | $19.26 |  | Swivel Loop, Copper-Plated Iron, Split-Ring Hanger - 22FP63|22FP63 - Grainger (https://www.grainger.com/product/22FP63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)
Hex Nut | Std Hex, 3/8"-16 Thread, Hex Nut - 1WB27|U51080.037.0001 - Grainger | 1WB27 | 1 | 16.01 | $16.01 |  | Std Hex, 3/8"-16 Thread, Hex Nut - 1WB27|U51080.037.0001 - Grainger (https://www.grainger.com/product/1WB27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)
Threaded Rod | Fully Threaded Rod: 3/8"-16 Thread Size, 3 ft Lg, Stainless Steel, 18-8, Plain - Grainger | 4RDG3 | 3 | 7.55 | $22.65 |  | https://www.grainger.com/product/4RDG3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
Copper Hanger Plate | Copper-Plated Iron, For 3/8 in Threaded Rod, Rod Hanger Plate - 22FP85|22FP85 - Grainger | 22FP85 | 12 | 3.55 | $42.60 |  | Copper-Plated Iron, For 3/8 in Threaded Rod, Rod Hanger Plate - 22FP85|22FP85 - Grainger (https://www.grainger.com/product/22FP85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)
Brass Union | Union, 1/2 in x 1/2 in, Metal Pipe Straight - 6RDA5|6RDA5 - Grainger | 6RDA5 | 1 | 50.51 | $50.51 |  | Union, 1/2 in x 1/2 in, Metal Pipe Straight - 6RDA5|6RDA5 - Grainger (https://www.grainger.com/product/6RDA5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)
Straight Coupling | Straight, 3/4 in x 1/2 in, Metal Pipe Straight - 6RCY9|6RCY9 - Grainger | 6RCY9 | 1 | 24.17 | $24.17 |  | Straight, 3/4 in x 1/2 in, Metal Pipe Straight - 6RCY9|6RCY9 - Grainger (https://www.grainger.com/product/6RCY9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)
Clear Tubing (10ft) | Clearbraid, PVC, Tubing - 796K77|K3150-12X10 - Grainger | 796K77 | 1 | 26.01 | $26.01 |  | Clearbraid, PVC, Tubing - 796K77|K3150-12X10 - Grainger (https://www.grainger.com/product/796K77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)
Hose Clamp | 201 Stainless Steel, Lined Band, Worm Gear Hose Clamp - 1XGY9|5316 - Grainger | 1XGY9 | 1 | 16.82 | $16.82 |  | 201 Stainless Steel, Lined Band, Worm Gear Hose Clamp - 1XGY9|5316 - Grainger (https://www.grainger.com/product/1XGY9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)
Barbed Hose Fitting | DIXON VALVE & COUPLING, For 3/4 in Hose I.D., Hose Barb x NPTF, Barbed Hose Fitting - 55EU91|1341212C - Grainger | 55EU91 | 2 | 25.17 | $50.34 |  | DIXON VALVE & COUPLING, For 3/4 in Hose I.D., Hose Barb x NPTF, Barbed Hose Fitting - 55EU91|1341212C - Grainger (https://www.grainger.com/product/55EU91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)
Barbed Hose Fitting | For 3/4 in Hose I.D., Hose Barb x NPT, Barbed Hose Fitting - 6AFN6|6AFN6 - Grainger | 6AFN6 | 2 | 12.5 | $25.00 |  | For 3/4 in Hose I.D., Hose Barb x NPT, Barbed Hose Fitting - 6AFN6|6AFN6 - Grainger (https://www.grainger.com/product/6AFN6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)
Screws | #10 Size, 5/8 in Lg, Cabinet Screw - 3KUK5|KK.MET.SCR.100 - Grainger | 3KUK5 | 1 | 28.56 | $28.56 |  | #10 Size, 5/8 in Lg, Cabinet Screw - 3KUK5|KK.MET.SCR.100 - Grainger (https://www.grainger.com/product/3KUK5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)
Hangers | Swivel Loop, Electro-Galvanized Iron, Split-Ring Hanger - 22FP59|22FP59 - Grainger | 22FP59 | 5 | 3.35 | $16.75 |  | Swivel Loop, Electro-Galvanized Iron, Split-Ring Hanger - 22FP59|22FP59 - Grainger (https://www.grainger.com/product/22FP59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)
Screws | #8 Size, 1 in Lg, Wood Screw - 31JG65|U51876.016.0100 - Grainger | 31JG65 | 1 | 14.81 | $14.81 |  | #8 Size, 1 in Lg, Wood Screw - 31JG65|U51876.016.0100 - Grainger (https://www.grainger.com/product/31JG65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)
Screws | #8 Size, 1 in Lg, Wood Screw - 31JG35|U51866.016.0100 - Grainger | 31JG35 | 1 | 19.99 | $19.99 |  | #8 Size, 1 in Lg, Wood Screw - 31JG35|U51866.016.0100 - Grainger (https://www.grainger.com/product/31JG35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)
Hanger Plate | Electrogalvanized Cast Iron, For 3/8 in Threaded Rod, Rod Hanger Plate - 1RUZ1|365M0037EG - Grainger | 1RUZ1 | 5 | 5.36 | $26.80 |  | Electrogalvanized Cast Iron, For 3/8 in Threaded Rod, Rod Hanger Plate - 1RUZ1|365M0037EG - Grainger (https://www.grainger.com/product/1RUZ1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)
Ball Valve | APOLLO, 3/4 in, Bronze, Manual Two-Way Ball Valve - 48XH63|77C10401A - Grainger | 48XH63 | 1 | 40.14 | $40.14 |  | APOLLO, 3/4 in, Bronze, Manual Two-Way Ball Valve - 48XH63|77C10401A - Grainger (https://www.grainger.com/product/48XH63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)
Flowmeter | Omega Flow Transmitter FLR6302D | eBay | N/A | 1 | 300 | $300.00 |  | Omega Flow Transmitter FLR6302D | eBay (https://www.ebay.com/itm/166028064956?_skw=FLR7330D&itmmeta=01KJG8GWDT78Z7AJAH1V586M94)
Nipple | Brass, 3/4 in Nominal Pipe Size, Pipe Nipple - 1VGT7|464-020 - Grainger | 1VGT7 | 6 | 11.53 | $69.18 |  | Brass, 3/4 in Nominal Pipe Size, Pipe Nipple - 1VGT7|464-020 - Grainger (https://www.grainger.com/product/1VGT7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)
Hanger Plate | Electrogalvanized Cast Iron, For 1/2 in Threaded Rod, Plate - 4UEG9|365M0050EG - Grainger | 4UEG9 | 2 | 4.75 | $9.50 |  | Electrogalvanized Cast Iron, For 1/2 in Threaded Rod, Plate - 4UEG9|365M0050EG - Grainger (https://www.grainger.com/product/4UEG9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)
Threaded Rod | 1/2"-13 Thread Size, 2 ft Lg, Fully Threaded Rod - 10W669|U51070.050.2400 - Grainger | 10W669 | 1 | 5.41 | $5.41 |  | 1/2"-13 Thread Size, 2 ft Lg, Fully Threaded Rod - 10W669|U51070.050.2400 - Grainger (https://www.grainger.com/product/10W669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)
Hex Nut | Std Hex, 1/2"-13 Thread, Hex Nut - 40TW73|U51080.050.0001 - Grainger | 40TW73 | 1 | 9.03 | $9.03 |  | Std Hex, 1/2"-13 Thread, Hex Nut - 40TW73|U51080.050.0001 - Grainger (https://www.grainger.com/product/40TW73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)
Drop-In Anchor | MKT FASTENING, 1/2"-13 Thread Size, 2 in Overall Lg, Drop-In Anchor - 30PK27|1312SS6 - Grainger | 30PK27 | 1 | 16.87 | $16.87 |  | MKT FASTENING, 1/2"-13 Thread Size, 2 in Overall Lg, Drop-In Anchor - 30PK27|1312SS6 - Grainger (https://www.grainger.com/product/30PK27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)
Screws | 1/2"-13 Thread Size, 3/4 in Lg, Machine Screw - 854J80|1-sfm-50c-75 - Grainger | 854J80 | 1 | 14.02 | $14.02 |  | 1/2"-13 Thread Size, 3/4 in Lg, Machine Screw - 854J80|1-sfm-50c-75 - Grainger (https://www.grainger.com/product/854J80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)
Adhesive | J-B WELD, ClearWeld, Ambient Cured, Epoxy Adhesive - 39F868|50112 - Grainger | 39F868 | 1 | 8.83 | $8.83 |  | J-B WELD, ClearWeld, Ambient Cured, Epoxy Adhesive - 39F868|50112 - Grainger (https://www.grainger.com/product/39F868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)
Adhesive | PC PRODUCTS, PC-SuperEpoxy, Ambient Cured, Epoxy Adhesive - 4AUW6|016619 - Grainger | 4AUW6 | 1 | 7.19 | $7.19 |  | PC PRODUCTS, PC-SuperEpoxy, Ambient Cured, Epoxy Adhesive - 4AUW6|016619 - Grainger (https://www.grainger.com/product/4AUW6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)
Hanger Plate | Iron, For 3/8 in Threaded Rod, Rod Hanger Plate - 22FP84|22FP84 - Grainger | 22FP84 | 4 | 2.76 | $11.04 |  | Iron, For 3/8 in Threaded Rod, Rod Hanger Plate - 22FP84|22FP84 - Grainger (https://www.grainger.com/product/22FP84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)
Barbed Hose Fitting | For 3/4 in Hose I.D., Hose Barb x NPT, Barbed Hose Fitting - 6AFL8|6AFL8 - Grainger | 6AFL8 | 2 | 3.49 | $6.98 |  | For 3/4 in Hose I.D., Hose Barb x NPT, Barbed Hose Fitting - 6AFL8|6AFL8 - Grainger (https://www.grainger.com/product/6AFL8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)
Tee | PARKER, Tee, 3/4 in x 3/4 in x 3/4 in, Metal Pipe Tee - 60WH38|2225P-12 - Grainger | 60WH38 | 1 | 42.76 | $42.76 |  | PARKER, Tee, 3/4 in x 3/4 in x 3/4 in, Metal Pipe Tee - 60WH38|2225P-12 - Grainger (https://www.grainger.com/product/60WH38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)
Pipe Cross | PARKER, Cross, 3/4 in x 3/4 in x 3/4 in x 3/4 in, Metal Pipe Cross - 13Y906|2205P-12 - Grainger | 13Y906 | 1 | 45.81 | $45.81 |  | PARKER, Cross, 3/4 in x 3/4 in x 3/4 in x 3/4 in, Metal Pipe Cross - 13Y906|2205P-12 - Grainger (https://www.grainger.com/product/13Y906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)
Barbed Hose Fitting | For 3/4 in Hose I.D., Hose Barb x NPT, Barbed Hose Fitting - 6AFP2|6AFP2 - Grainger | 6AFP2 | 1 | 18.73 | $18.73 |  | For 3/4 in Hose I.D., Hose Barb x NPT, Barbed Hose Fitting - 6AFP2|6AFP2 - Grainger (https://www.grainger.com/product/6AFP2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)
Pipe Clamp | Swivel Loop, Electro-Galvanized Steel, Pipe Clamp - 1RVC2|454005 - Grainger | 1RVC2 | 1 | 4.99 | $4.99 |  | Swivel Loop, Electro-Galvanized Steel, Pipe Clamp - 1RVC2|454005 - Grainger (https://www.grainger.com/product/1RVC2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)
Pipe Clamp | Swivel Loop, Electro-Galvanized Steel, Pipe Clamp - 1RVC1|454004 - Grainger | 1RVC1 | 1 | 4.68 | $4.68 |  | Swivel Loop, Electro-Galvanized Steel, Pipe Clamp - 1RVC1|454004 - Grainger (https://www.grainger.com/product/1RVC1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)
Channel Fitting | Silver, Electro Galvanized, Strut Channel Fitting - 793VU2|V717EG - Grainger | 793VU2 | 1 | 39.72 | $39.72 |  | Silver, Electro Galvanized, Strut Channel Fitting - 793VU2|V717EG - Grainger (https://www.grainger.com/product/793VU2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)
Screws | #8 Size, 3/4 in Lg, Wood Screw - 31JG34|U51866.016.0075 - Grainger | 31JG34 | 1 | 15.07 | $15.07 |  | #8 Size, 3/4 in Lg, Wood Screw - 31JG34|U51866.016.0075 - Grainger (https://www.grainger.com/product/31JG34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)
Spring Nut | 3/8"-16 Thread Size, 3/8 in Bolt Size, Spring Nut - 5YE11|V200 3/8 - Grainger | 5YE11 | 1 | 45.58 | $45.58 |  | 3/8"-16 Thread Size, 3/8 in Bolt Size, Spring Nut - 5YE11|V200 3/8 - Grainger (https://www.grainger.com/product/5YE11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)
Washer | 18-8, Stainless Steel, Flat Washer - 22UG07|U51410.037.0001 - Grainger | 22UG07 | 1 | 6.43 | $6.43 |  | 18-8, Stainless Steel, Flat Washer - 22UG07|U51410.037.0001 - Grainger (https://www.grainger.com/product/22UG07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)
Hex Screw | Stainless Steel, A2, Hex Head Cap Screw - 3AUW4|U51000.037.0100 - Grainger | 3AUW4 | 1 | 26.5 | $26.50 |  | Stainless Steel, A2, Hex Head Cap Screw - 3AUW4|U51000.037.0100 - Grainger (https://www.grainger.com/product/3AUW4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)
Compartment Box | PLANO MOLDING, 11 in x 7 1/4 in x 1 3/4 in, Clear, Compartment Box - 30F070|2-3600-01 - Grainger | 30F070 | 2 | 12.8 | $25.60 |  | PLANO MOLDING, 11 in x 7 1/4 in x 1 3/4 in, Clear, Compartment Box - 30F070|2-3600-01 - Grainger (https://www.grainger.com/product/30F070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)
Screws | #10 Size, 1 in Lg, Wood Screw - 31JG71|U51876.019.0100 - Grainger | 31JG71 | 1 | 14.16 | $14.16 |  | #10 Size, 1 in Lg, Wood Screw - 31JG71|U51876.019.0100 - Grainger (https://www.grainger.com/product/31JG71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)
Threaded Rod | 3/8"-16 Thread Size, 2 ft Lg, Fully Threaded Rod - 10W663|U51070.037.2400 - Grainger | 10W663 | 5 | 6.98 | $34.90 |  | 3/8"-16 Thread Size, 2 ft Lg, Fully Threaded Rod - 10W663|U51070.037.2400 - Grainger (https://www.grainger.com/product/10W663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)
Nipple (2") | Schedule 80, CPVC, Pipe Nipple - 6MX55|9861-020 - Grainger | 6MX55 | 1 | 3.76 | $3.76 |  | Schedule 80, CPVC, Pipe Nipple - 6MX55|9861-020 - Grainger (https://www.grainger.com/product/6MX55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)
Nipple (3") | Schedule 80, CPVC, Pipe Nipple - 6MX66|9861-106 - Grainger | 6MX66 | 1 | 4.72 | $4.72 |  | Schedule 80, CPVC, Pipe Nipple - 6MX66|9861-106 - Grainger (https://www.grainger.com/product/6MX66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)
Flange | 1 1/2 in, Carbon Steel, Metal Pipe Flange - 30WH23|151-012-000 - Grainger | 30WH23 | 2 | 61.04 | $122.08 |  | 1 1/2 in, Carbon Steel, Metal Pipe Flange - 30WH23|151-012-000 - Grainger (https://www.grainger.com/product/30WH23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)
304 Pipe | 304 Stainless Steel, Schedule 40, Pipe - 782G46|T4PPH06WD - Grainger | 782G46 | 1 | 382.26 | $382.26 |  | 304 Stainless Steel, Schedule 40, Pipe - 782G46|T4PPH06WD - Grainger (https://www.grainger.com/product/782G46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)
Pipe Straight | 1 1/2 in x 1 1/2 in, Butt Weld x Butt Weld, Metal Pipe Straight - 1RTU2|4381023840 - Grainger | 1RTU2 | 2 | 47.78 | $95.56 |  | 1 1/2 in x 1 1/2 in, Butt Weld x Butt Weld, Metal Pipe Straight - 1RTU2|4381023840 - Grainger (https://www.grainger.com/product/1RTU2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)
DIN Rail | DIN Rail Mounting, Aluminum, Mounting Track - 18Z758|18Z758 - Grainger | 18Z758 | 5 | 9.99 | $49.95 |  | DIN Rail Mounting, Aluminum, Mounting Track - 18Z758|18Z758 - Grainger (https://www.grainger.com/product/18Z758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)
Nipple | 3/4 in Nominal Pipe Size, Male NPT, Pipe Nipple - 793MY3|793MY3 - Grainger | 793MY3 | 1 | 6.02 | $6.02 |  | 3/4 in Nominal Pipe Size, Male NPT, Pipe Nipple - 793MY3|793MY3 - Grainger (https://www.grainger.com/product/793MY3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)
Pipe Straight | 3/4 in x 3/4 in, Threaded x Threaded, Metal Pipe Straight - 5P553|5P553 - Grainger | 5P553 | 1 | 2.32 | $2.32 |  | 3/4 in x 3/4 in, Threaded x Threaded, Metal Pipe Straight - 5P553|5P553 - Grainger (https://www.grainger.com/product/5P553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)
M12 4 Pin Connector | M12 Female Straight 4 Pin Connector Aviation Electrical Socket Cable 2M / 5' | eBay | N/A | 4 | 11.99 | $47.96 |  | M12 Female Straight 4 Pin Connector Aviation Electrical Socket Cable 2M / 5' | eBay (https://www.ebay.com/itm/156665159304?emsid=e11401.m144671.l197929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)
Pipe Straight | Straight, 1/2 in x 1/4 in, Metal Pipe Straight - 46M483|706110-0804 - Grainger | 46M483 | 1 | 9.99 | $9.99 |  | Straight, 1/2 in x 1/4 in, Metal Pipe Straight - 46M483|706110-0804 - Grainger (https://www.grainger.com/product/46M483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)
Bushing | Straight, 3/4 in x 1/4 in, Metal Pipe Straight - 1VFX8|1VFX8 - Grainger | 1VFX8 | 2 | 14.63 | $29.26 |  | Straight, 3/4 in x 1/4 in, Metal Pipe Straight - 1VFX8|1VFX8 - Grainger (https://www.grainger.com/product/1VFX8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)
Pressure Transducer | OEM Style, Compact Pressure Transmitters with Mini DIN | PX159A-060G5V | 4 | 167.42 | $669.68 |  | OEM Style, Compact Pressure Transmitters with Mini DIN (https://www.dwyeromega.com/en-us/oem-style-compact-pressure-transmitters/PX119/p/PX159A-060G5V)
Screws | Stainless Steel, A2, Hex Tap Bolt - 41UH04|U51010.050.0300 - Grainger | 41UH04 | 1 | 12.61 | $12.61 |  | Stainless Steel, A2, Hex Tap Bolt - 41UH04|U51010.050.0300 - Grainger (https://www.grainger.com/product/Hex-Tap-Bolt-Stainless-Steel-41UH04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)
Terminal Bridges |  | FBS10-5 | 2 | 10.45 | $20.90 |  | N/A
USB hub | Eaton Tripp Lite Series 4-Port Industrial-Grade USB 3.x (5Gbps) Hub - 20 kV ESD Immunity, Metal Housing, Mountable | U360-004-IND | 1 | $110.00 | $110.00 |  | https://www.cdwg.com/product/tripp-lite-4-port-industrial-usb-3.0-superspeed-hub-15kv-esd-immunity-metal/3682489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

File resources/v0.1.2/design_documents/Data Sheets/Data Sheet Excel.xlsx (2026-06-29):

Name | Link
TCR Power Supply 10T500 Data Sheet | https://www.us.lambda.tdk.com/products/legacy-products/pdf/tcr.pdf
W10MT Variac Autotansformers Data Sheet | https://www.ietlabs.com/pdf/Manuals/GR/W10%20Series%20Variac%20Autotansformers.pdf
US General Series 3 Toolbox Data Sheet | https://manuals.harborfreight.com/manuals/70000-70999/70736-193175567642.pdf
Yukon 46" 9 Drawer Toolbox Data Sheet | https://manuals.harborfreight.com/manuals/57000-57999/57805-193175422521.pdf
Cameron-Aufnehmer-MC-II Flow Transmitter-TechnicalDataSheet | http://www.durchfluss.de/doc/Cameron-Aufnehmer-TechnicalDataSheet.pdf
Omega Engineering Flow Transmitter | https://assets.dwyeromega.com/spec/FLR-D+(1).pdf
Burkert DS8605 Data Sheet | https://www.burkert.com/en/Media/plm/DTS/DS/ds8605-standard-eu-en.pdf?id=DTS0000000000000001000086949ENP
ITT-SSCF-Heat-Ecchanger Data Sheet | https://www.ittheatexchangers.com/shell_tube/SSCF/ITT-SSCF-Series.pdf
Mean Well EDR-120-12 Data Sheet | https://www.meanwell.com/Upload/PDF/EDR-120/EDR-120-SPEC.PDF
Mean Well NDR-120-SPEC Data Sheet | https://www.meanwell.com/Upload/PDF/NDR-120/NDR-120-SPEC.PDF
National_Instruments_cdaq-9174_data_sheet | https://www.ni.com/docs/en-US/bundle/cdaq-9174-specs/page/specs.html

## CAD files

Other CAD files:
resources/v0.1.0/CAD_models/V0.1.0/Fusion/aa FINAL MODEL.f3z
resources/v0.1.0/CAD_models/V0.1.0/Inventor/.iam files/Air Exhaust Valve.iam
resources/v0.1.0/CAD_models/V0.1.0/Inventor/.iam files/Average Flange Component (Larger Nut).iam
resources/v0.1.0/CAD_models/V0.1.0/Inventor/.iam files/Average Flange Component (Larger Nut)1.iam
resources/v0.1.0/CAD_models/V0.1.0/Inventor/.iam files/Average Flange Component (Larger Nut)2.iam
resources/v0.1.0/CAD_models/V0.1.0/Inventor/.iam files/Average Flange Component (Larger Nut)3.iam
resources/v0.1.0/CAD_models/V0.1.0/Inventor/.iam files/Average Flange Component (Larger Nut)4.iam
resources/v0.1.0/CAD_models/V0.1.0/Inventor/.iam files/Average Flange Component (Larger Nut)5.iam
resources/v0.1.0/CAD_models/V0.1.0/Inventor/.iam files/Average Flange Component (Larger Nut)6.iam
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

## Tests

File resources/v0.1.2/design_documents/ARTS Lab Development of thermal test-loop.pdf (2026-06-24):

## Thermal Test Loop Overview

Optional subhead

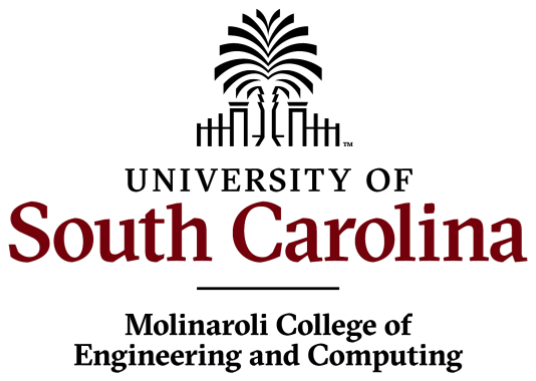
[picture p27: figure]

1

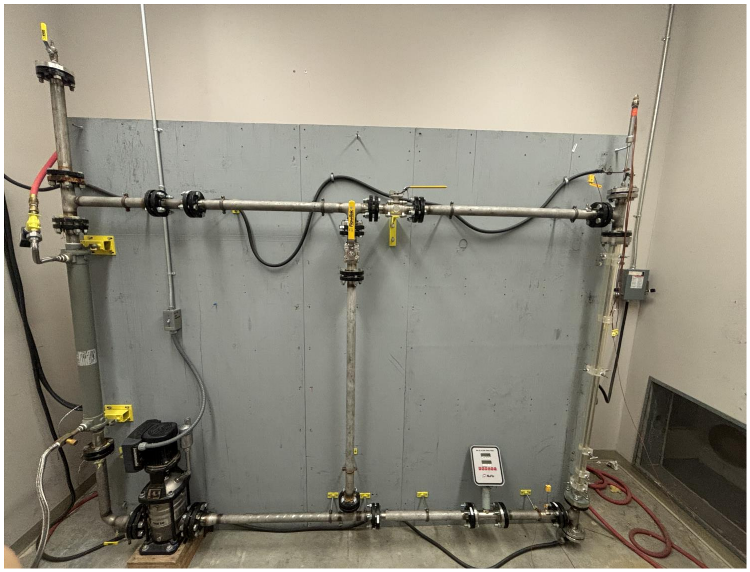
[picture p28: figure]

## Current Setup

- C004g @ 300 main
- Closed Loop
- Developed first by Dr.
Leo Carrilho in *2005*

2

## Current Setup

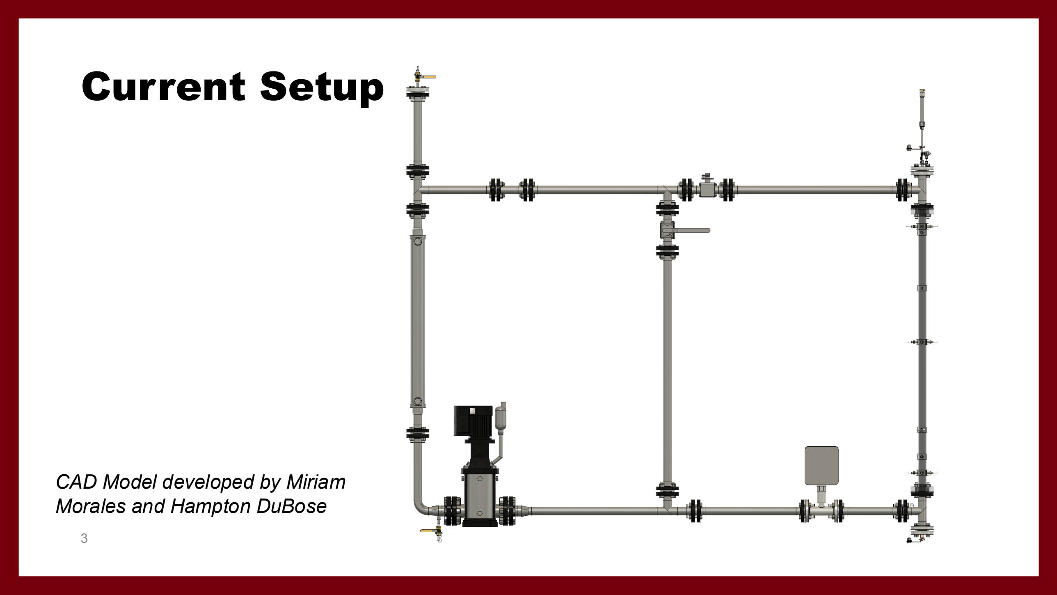
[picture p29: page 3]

3

CAD Model developed by Miriam Morales and Hampton DuBose

## Component Breakdown

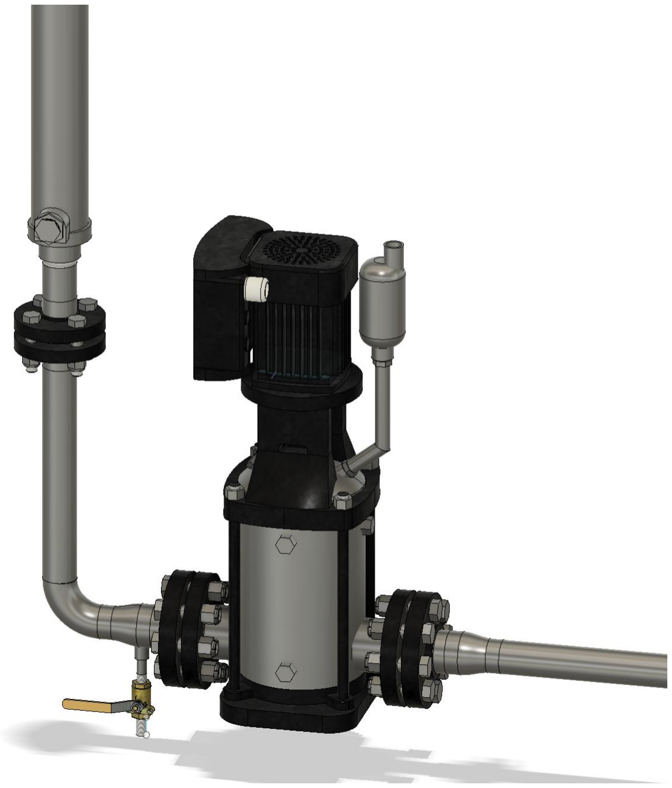
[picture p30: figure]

## Fluid Pump

- Drives coolant fluid through fuel rod containment
- Max Flowrate:14-15 m^3/hr
- 0.75 hp

5

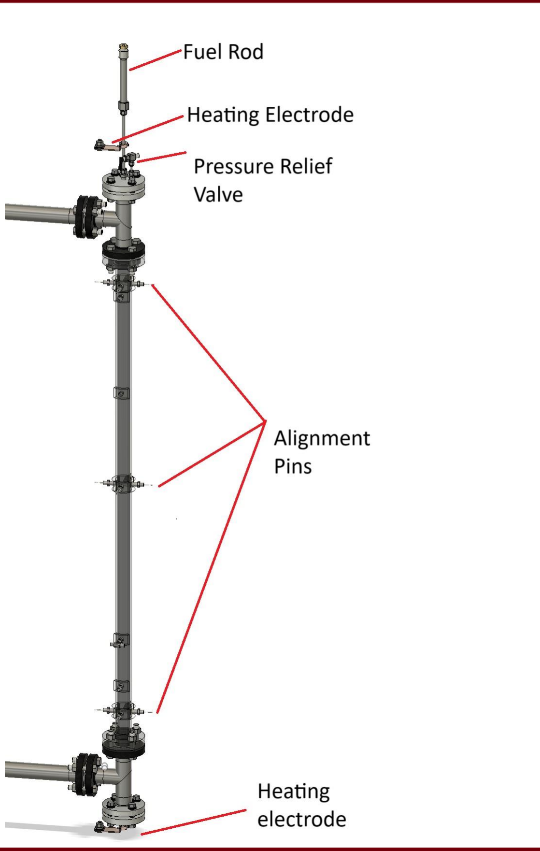
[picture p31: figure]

## Energy Source-'Reactor vessel'

- Single fuel rod secured in channel
- Plexiglass pipe for visibility
- Resistive heating adds
energy to water
- Interchangeable system for testing different fuel rods
- Has channels for pressure measurements

6

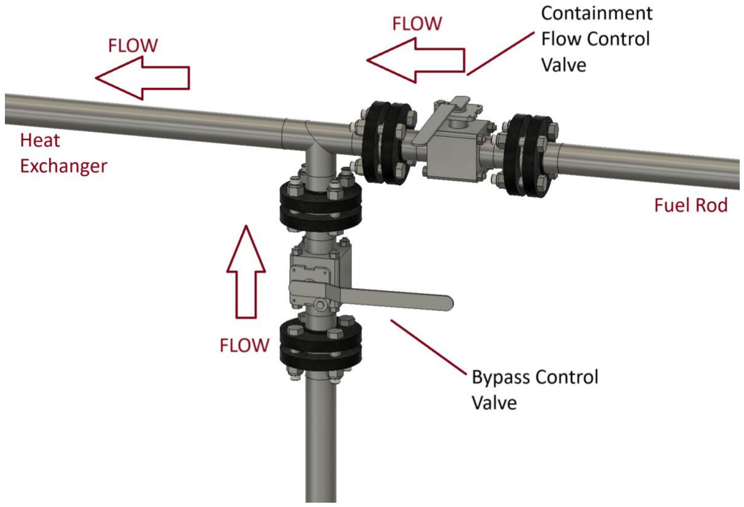
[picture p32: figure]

## Flow Control Valves

- Vertical valve
shuts/opens bypass
channel
- Changes flow rate
through heat source
- Containment Control
Valve governs flow
through heat source
- Blockage simulation

7

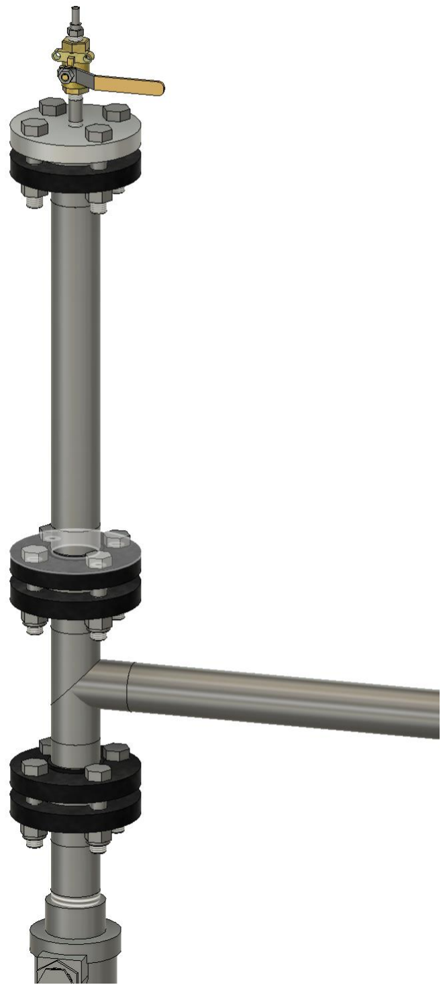
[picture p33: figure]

## Pressurizer

- Air Hose Attachment on
top
- Raises boiling point of
water by pressurizing
entire system w/ Air
- Increases efficiency of
real reactors

8

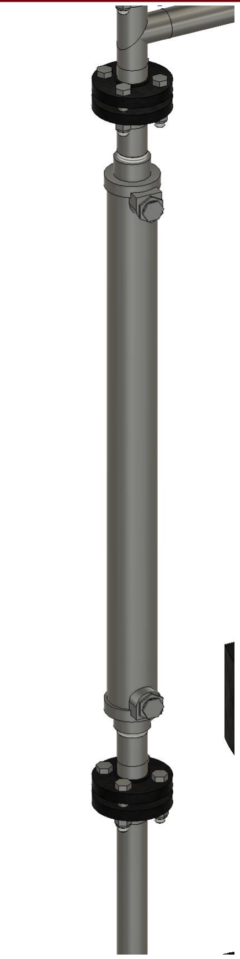
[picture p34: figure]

## Heat Exchanger

- Tap water pulls heat
from the loop
- 1 m^2 of heat transfer
area
- Water is expelled outside

9

## Typical PWR System

10

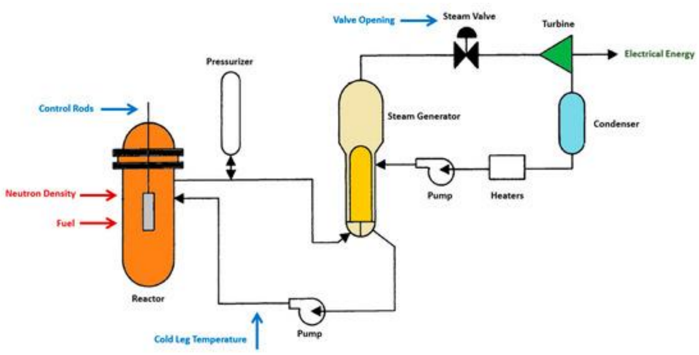
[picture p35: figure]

## Plan for expansion to add measurement instruments

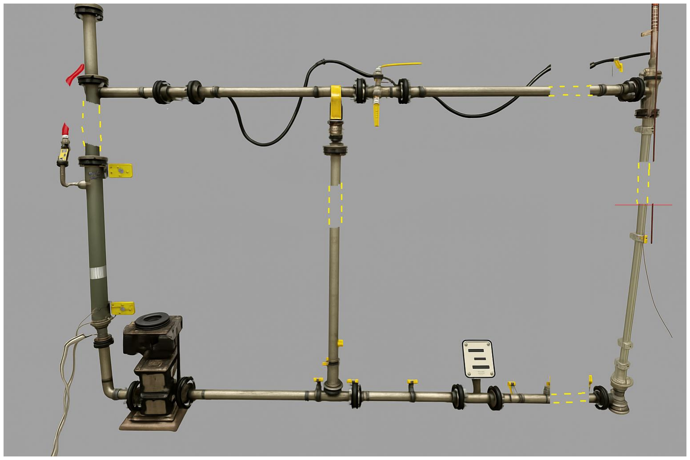
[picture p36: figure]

- Add lengths of pipe to
both horizontal and all
three vertical pipes to
Improve measurement
capability at different
locations along the
loop

11

## Plan to add 'Control Room'

12


- Develop
remote
control and
monitoring
capabilities
- Located in
C004 or
Nearby

## Thank You for Your Time

Name: Matthew Whetham

Title: Undergrad, DME
Email: mwhetham@email.sc.edu
Lab GitHub: github.com/arts-laboratory


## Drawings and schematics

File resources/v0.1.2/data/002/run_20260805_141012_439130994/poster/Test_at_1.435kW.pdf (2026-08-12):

## Loop response to heat exchanger flow reduction

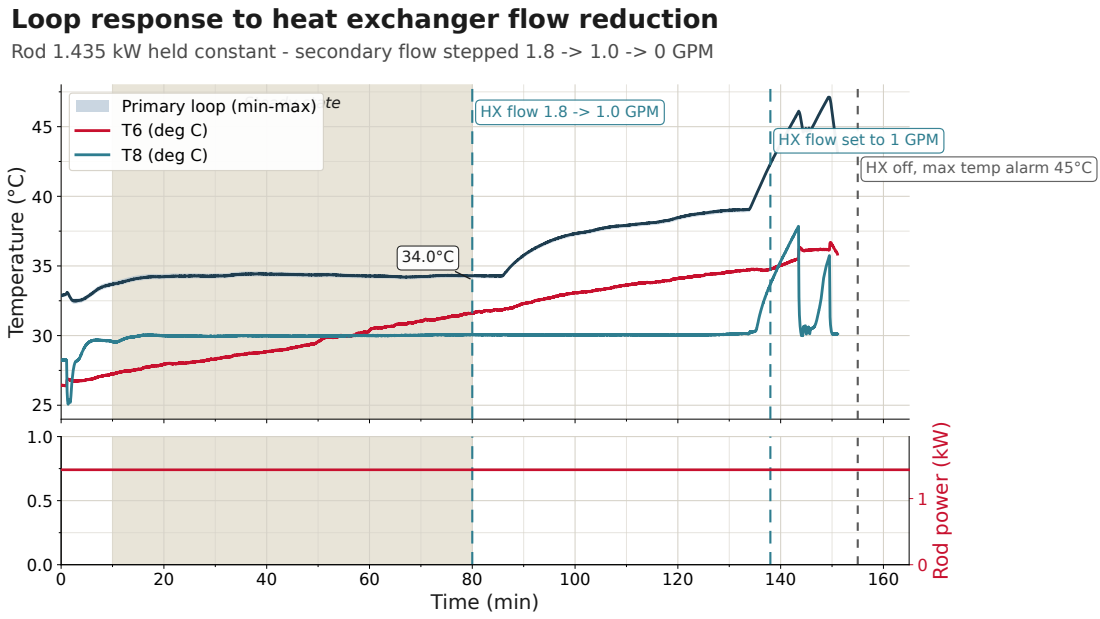
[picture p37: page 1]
Temperature (°C); Time (min)

Rod 1.435 kW held constant - secondary flow stepped 1.8 -> 1.0 -> 0 GPM

Primary loop (min-max) Steady state | HX flow 1.8 -> 1.0 GPM
T6 (deg C) T8 (deg C)

HX flow set to 1 GPM

HX off, max temp alarm 45°C

Rod power (kW)

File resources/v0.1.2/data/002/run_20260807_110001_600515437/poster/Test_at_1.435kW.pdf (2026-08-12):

## Loop response to heat exchanger flow reduction

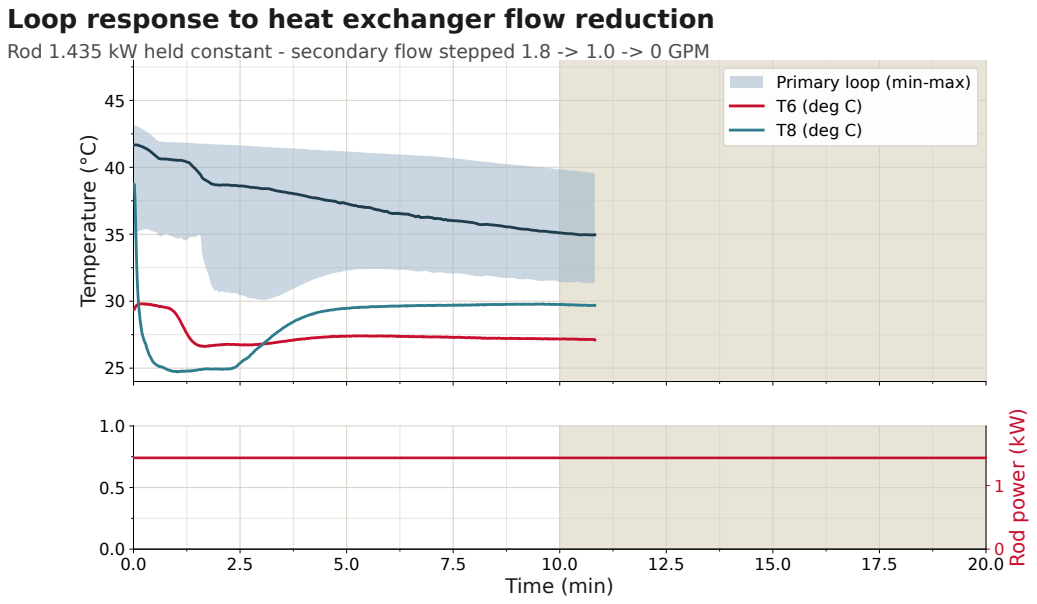
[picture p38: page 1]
Temperature (°C); Primary loop (min-max); Steady state; T6 (deg C) T8 (deg C); Time (min)

Rod 1.435 kW held constant - secondary flow stepped 1.8 -> 1.0 -> 0 GPM

Rod power (kW)

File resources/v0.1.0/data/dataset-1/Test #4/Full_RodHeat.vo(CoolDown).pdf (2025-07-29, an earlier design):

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

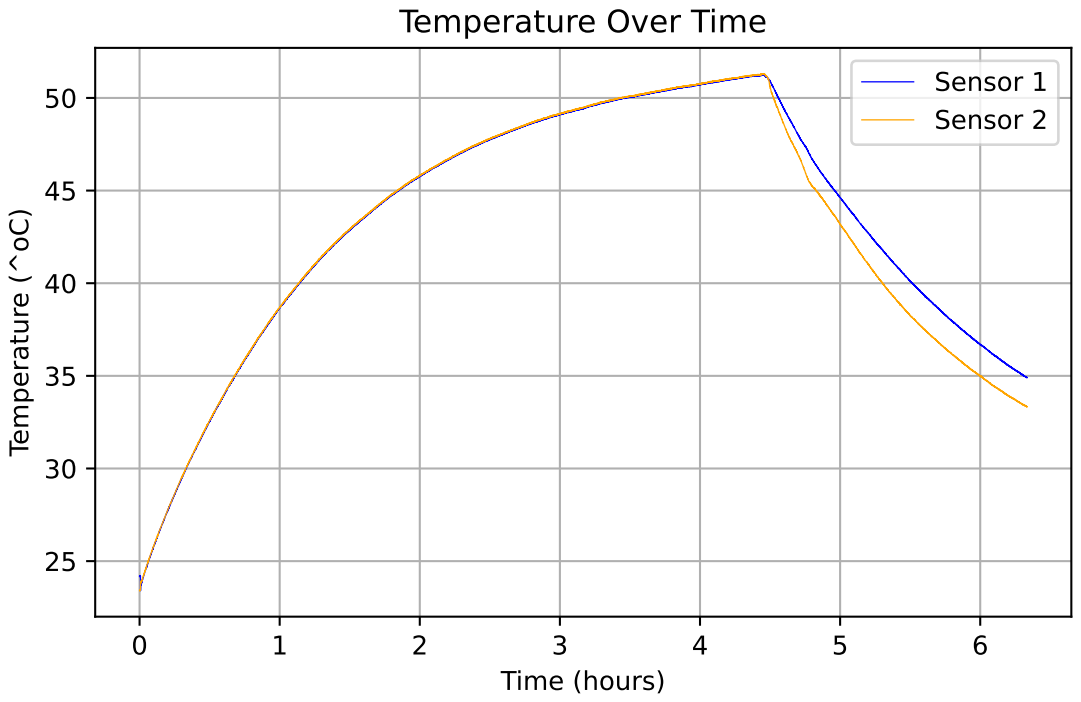
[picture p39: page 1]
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

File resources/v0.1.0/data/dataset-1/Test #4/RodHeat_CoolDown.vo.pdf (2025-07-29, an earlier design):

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

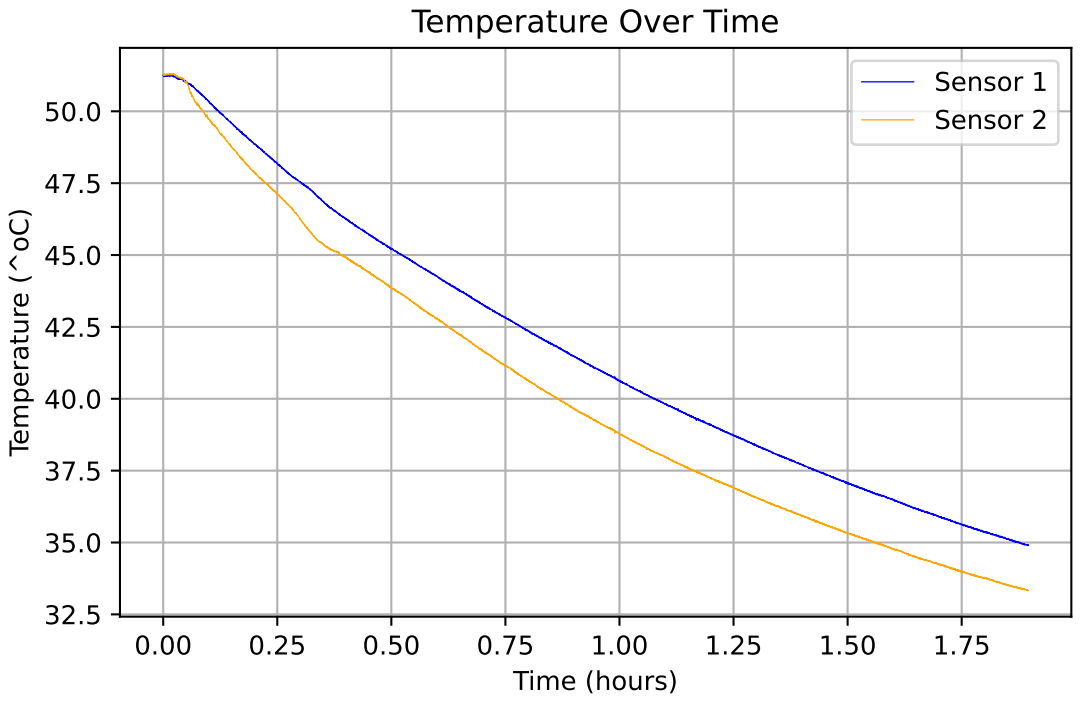
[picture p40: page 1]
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

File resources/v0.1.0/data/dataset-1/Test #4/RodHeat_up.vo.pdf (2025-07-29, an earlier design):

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

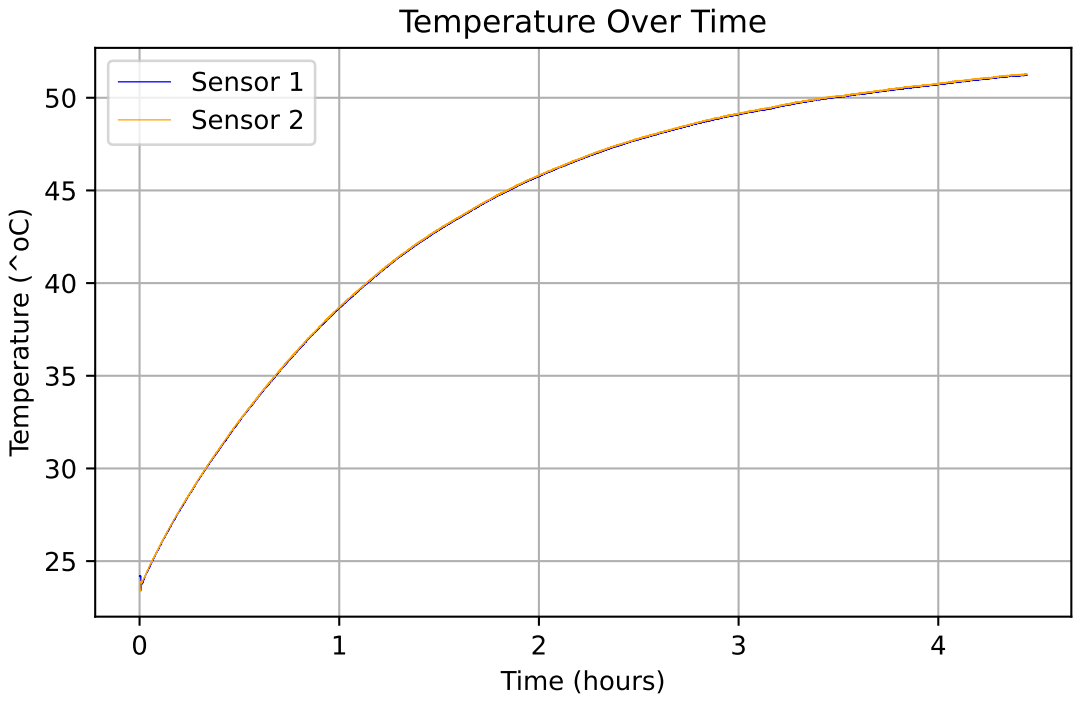
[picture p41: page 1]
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

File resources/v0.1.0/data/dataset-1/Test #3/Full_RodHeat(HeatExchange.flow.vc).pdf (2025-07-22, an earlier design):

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

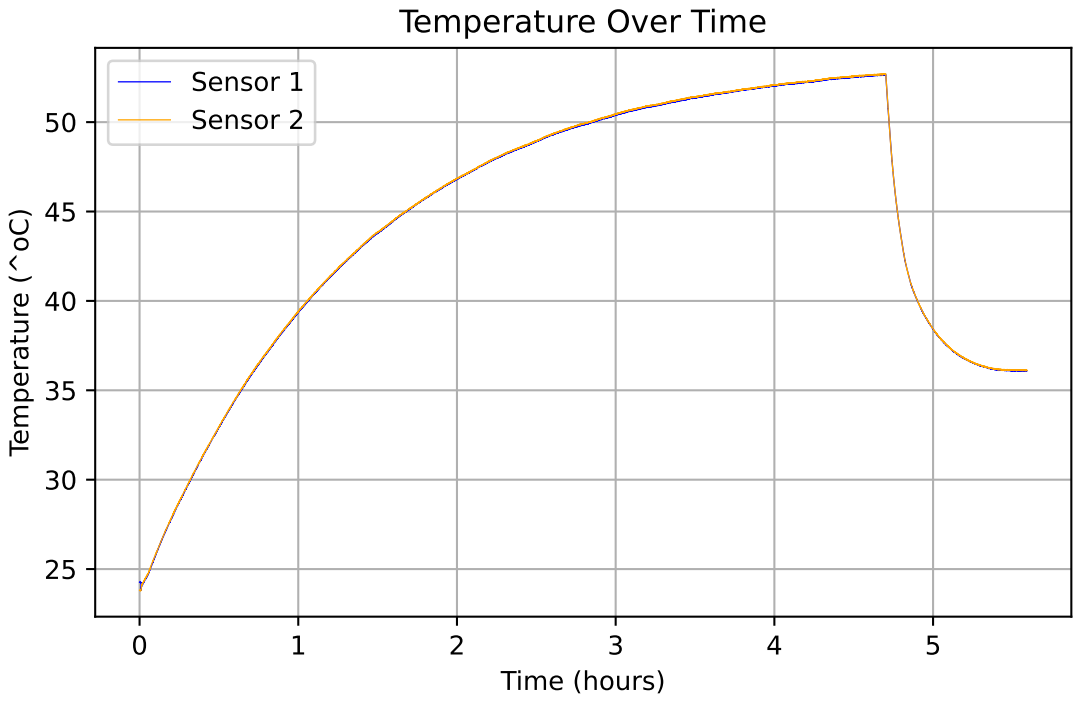
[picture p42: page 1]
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

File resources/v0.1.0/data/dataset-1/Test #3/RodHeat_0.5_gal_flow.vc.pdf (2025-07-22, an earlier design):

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

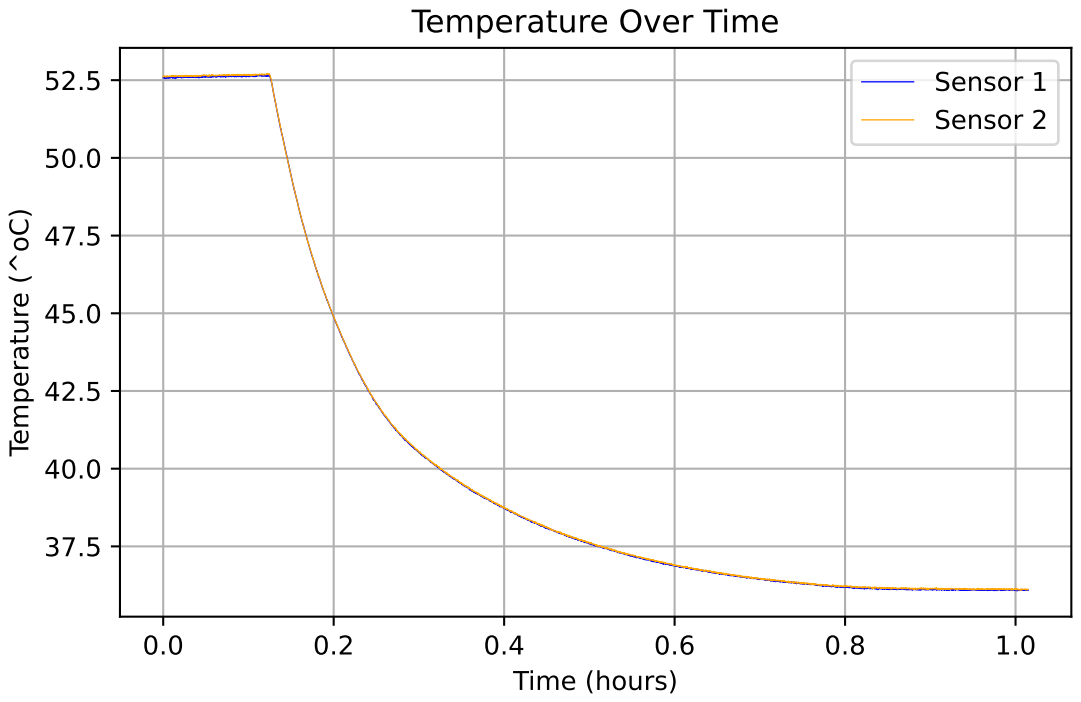
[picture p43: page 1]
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

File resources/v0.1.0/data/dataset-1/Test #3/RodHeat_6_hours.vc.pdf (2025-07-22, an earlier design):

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

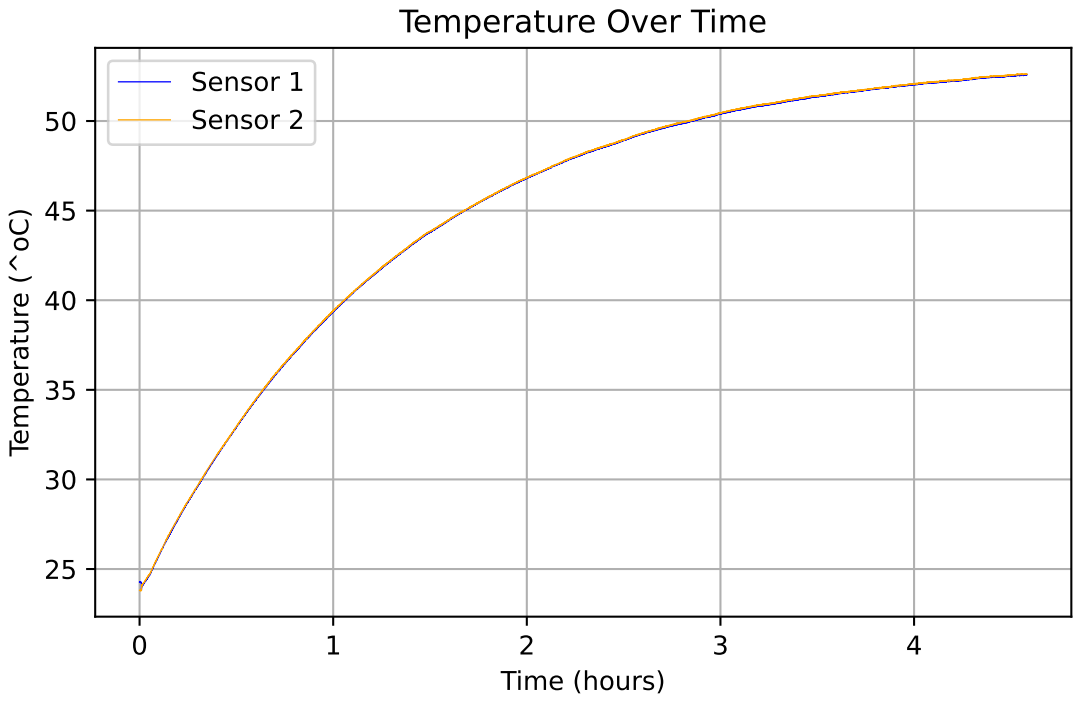
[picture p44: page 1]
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

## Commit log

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2026-01-06 added BOM
    [BOM-thermal-loop.xlsx]
2026-02-04 Add files via upload
    Wiring Duct added to BOM
    [BOM-thermal-loop (1).xlsx]
2026-02-04 Outdated BOM
    [BOM-thermal-loop.xlsx]
2026-02-04 Rename Updated BOM
    [BOM-thermal-loop .xlsx]
2026-03-02 Delete resources/design_documents/BOM-thermal-loop .xlsx
    Deleted for updated version
    [BOM-thermal-loop .xlsx]
2026-03-02 Add files via upload
    Updated BOM
    [BOM-thermal-loop .xlsx]
2026-06-01 moved cad model to v0.1.1.
    [1 1_2 Black Flange.ipt, 1 1_2 Black Flange1.ipt, 1 1_2 Silver Flange.ipt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]
2026-06-01 removed fusion models form v0.1.1
    [aa FINAL MODEL.f3z]
2026-06-02 Inventor 3D model Files update
    [1 1_2 Black Flange v3.ipt, 1 1_2 Black Flange v6.ipt, 1 1_2 Black Flange.ipt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]
2026-06-03 Delete resources/design_documents/BOM-thermal-loop .xlsx
    Deleted for new and improved BOM
    [BOM-thermal-loop .xlsx]
2026-06-03 Add files via upload
    New, completely updated BOM with every order
    [BOM-thermal-loop updated 6-3.xlsx]
2026-06-24 created version 0.1.1
    [1 1_2 Black Flange v3.ipt, 1 1_2 Black Flange v6.ipt, 1 1_2 Black Flange.ipt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]
2026-06-25 Updated model
    The Final model with the extensions and new pipe has been added to the repository
    [1 1_2 Black Flange v3.ipt, 1 1_2 Black Flange v6.ipt, 1 1_2 Black Flange v8.ipt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]
2026-06-26 Monitior Stand ipt and iam files
    [25.4 inch T-Slotted Framing Rail.ipt, 36 inch T-Slotted Framing Rail.0001.ipt, 36 inch T-Slotted Framing Rail.ipt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]
2026-06-28 Data Sheets for Thermal Loop Room
    [Data Sheet Excel.xlsx]
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2026-07-02 general clean up
    [25.4 inch T-Slotted Framing Rail.ipt, 36 inch T-Slotted Framing Rail.0001.ipt, 36 inch T-Slotted Framing Rail.ipt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]
2026-07-02 updated BOM to new style
    [BOM-thermal-loop_v0.1.1.xlsx]
2026-07-02 Updated Data Acquisition
    [flow.csv, pressure.csv, temperature.csv]
2026-07-06 7/6/26 Update
    Most stable version of the model by far. Proportional valve opens when it's supposed to and the internal loop temperature stays nearly constant over long test cycles. Will test further to find any more cracks in the foundation but this model works well.
2026-07-07 Test 1
    [flow.csv, pressure.csv, temperature.csv]
2026-07-07 New LabVIEW V6.75
    [flow.csv, pressure.csv, temperature.csv]
2026-07-09 LabVIEW work
    [flow.csv, pressure.csv, temperature.csv]
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2026-07-14 Create BOM-thermal-loop updated 7-14.xlsx
    [BOM-thermal-loop updated 7-14.xlsx]
2026-07-14 updated LabVIEW
    [flow.csv, pressure.csv, temperature.csv]
2026-07-15 labview update
    [flow.csv, pressure.csv, temperature.csv]
2026-07-16 updated BOM
    [BOM-thermal-loop updated 6-3.xlsx, BOM-thermal-loop updated 7-14.xlsx, BOM-thermal-loop updated 7-16.xlsx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]
2026-07-16 updated BOM layout
    [BOM-V0.1.1.xlsx, BOM-thermal-loop updated 7-16.xlsx]
2026-07-20 Zinc Nuts and Smaller Washers
    [BOM-V0.1.1.xlsx]
2026-07-20 Model Update and v.0.1.2 added
    Model with pressure relief attached to the extension piece. v0.1.2 was added
    [1 1_2 Black Flange v3.ipt, 1 1_2 Black Flange v8.ipt, 1 1_2 Silver Flange v2.ipt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]
2026-07-20 Replaced previous BOM
    [BOM-V0.1.1.xlsx, BOM-V0.1.2.xlsx]
2026-07-20 BOM Update
    [BOM-V0.1.1.xlsx, BOM-V0.1.2.xlsx]
2026-07-27 Model Update
    The model in v0.1.2 was updated to contain sensors across the loop
    [0-200 PSI transducers v1.ipt, 0-60 PSI Transducer v2.ipt, 1 1_2 Black Flange v3.ipt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]
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2026-07-29 testing + LabVIEW update
    [flow.csv, pressure.csv, temperature.csv]
2026-07-29 CAD Model and Data Sheet
    One model for the cDAQ and a data sheet for the Grinnell 3/4 inch valve and a data sheet for the Flow-Tek ball valve.
    [cd_cdaq-9174_compactdaq.ipt]
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2026-07-30 Model Update
    The model now contains the proportional valve setup and updated heat exchanger piping
    [0-200 PSI transducers v1.ipt, 0-60 PSI Transducer v2.ipt, 002_WASHERS_ALL_SO_7_INCH.ipt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]
2026-07-30 Updated BOM
    With Brass Rod and Compression Fittings
    [BOM-V0.1.2.xlsx]
2026-07-31 Removed Empty Rows for BOM
    [BOM-V0.1.2.xlsx]
2026-08-05 labVIEW update + readme
    [flow.csv, pressure.csv, temperature.csv]
2026-08-05 Labview test!
    data folder in both 0.1.1 and 0.1.2
    [flow.csv, pressure.csv, temperature.csv]
2026-08-06 testing and also labview changes
    [flow.csv, pressure.csv, temperature.csv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]
2026-08-07 labview updates and small test
    [flow.csv, pressure.csv, temperature.csv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]
2026-08-10 Addition of pressure relief on the left hand side.
    [Pressure Relief v13.0002.iam, Pressure Relief v13.iam, Welded Extension Section w_ relief v10.0001.iam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]
2026-08-10 cleanup and graphing tests
    [Extension Piece v2.f3z, aa FINAL MODEL extensions and Pipe.iam, flow.csv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]
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2026-08-12 Pressure relief and name change to data sheet
    Pressure relief has been added to the left side of the assembly and the data sheet for the CRIE pump has been renamed.
    [aa FINAL MODEL with drainage extension.0002.iam, aa FINAL MODEL with drainage extension.0003.iam, aa FINAL MODEL with drainage extension.iam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]
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2026-08-17 Updates
    Added a new pressure relief and the brass rods to the assembly of the thermal loop.
    [Heater Connection Flange w_ rod v8.0001.iam, Heater Connection Flange w_ rod v8.iam, aa FINAL MODEL with drainage extension.0003.iam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]
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2026-08-21 labview fixed to reflect newly added cDAQ
    [flow.csv, pressure.csv, temperature.csv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]
2026-08-25 Some test data from v4 and v5 adds turbine pressure expansion
    Both of these run on the SpeedGoat which indicates decent stability.
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
